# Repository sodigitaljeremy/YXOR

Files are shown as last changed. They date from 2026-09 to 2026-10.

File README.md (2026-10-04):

# YXOR

Robot humanoïde bipède autonome à IA embarquée locale.

> **À lire en premier : ce fichier (où en est le robot), puis
> [les décisions actives](docs/decisions.md) (ce qui est décidé, par
> qui).** La vision et la méthode sont dans [le cadrage](docs/cadrage.md).

## Où en est le robot — 2026-10-01

Le robot n'est pas dessiné à une taille choisie d'avance : **chaque
classe d'actionneur fixe la taille qu'elle porte** (`scripts/dimensionnement.py`,
marge 1,5). Quatre tailles :

| Taille | H | Actionneur de jambe | Statut |
| --- | --- | --- | --- |
| **S** | **0,60 m** (repli 0,55 m) | **RobStride RS02** au roulis et au tangage de hanche et au genou, **RS00** au lacet de hanche et au tangage de cheville ; 5 axes par jambe | **décidé** (fiches 0067 et 0068), premier robot |
| M | ~0,80 m | RS02 ou équivalent | ordre de grandeur |
| L | ~0,90 m | RS06, ou mixte RS06/RS02 | ordre de grandeur |
| XL | ≥ 1,0 m | RS03 et au-delà | hors programme |

Les hauteurs sont dans `params/anthropometry.yaml`.

**S, la v1 : 10 degrés de liberté**, 5 par jambe, sans bras : pas de
roulis de cheville (fiche 0068, Jeremy, 2026-10-04). Un degré de liberté
est une articulation motorisée.

- **Masse calculée : 6,75 kg à 0,60 m** en v1 (buste fixe), dont 1,2 kg
  de charge utile ; la jambe porterait jusqu'à 0,80 m. Avec l'hypothèse
  d'un haut du corps en RS05 (v3, 26 DDL) : 9,8 kg, 0,68 m portés.
  Actionneurs de jambe : 1 224 CHF HT. L'effort de roulis de cheville de
  la marche de référence est écarté, non reporté : hypothèse non vérifiée. La charge utile (calculateur,
  batterie, IMU) est une hypothèse de travail.
- **Le couple continu, la pointe, la charge utile et le relevé passent à
  0,60 m**, en v1 comme en v3 ; l'articulation limitante est le tangage
  de cheville. Grille et hypothèses :
  [`docs/choix-actionneurs.md`](docs/choix-actionneurs.md).
- **Restent ouverts** : la composition du banc, qui ne couvre que le
  RS00 ; une seconde marche de référence avant l'achat des 12 moteurs
  (proposé) ; la version exacte du RS00 (deux sont publiées) ; les tâches
  des bras ; les composants réels de la charge utile.

**Fabriqué à ce jour** : une pièce d'apprentissage, la semelle. Ni
assemblage ni nomenclature.

**La refonte du dépôt est terminée** (2026-10-01, étiquettes Git
`avant-refonte-2026-10-01` et `apres-refonte-2026-10-01`). Le diagnostic
qui l'a lancée est dans `archive/docs/`.

**Prochaine étape** (PROPOSÉE par Claude Code, non décidée) :

- la couche logicielle d'articulation et son backend MuJoCo, sans aucun
  achat ;
- puis la première pièce de jambe à H_S ;
- puis le banc de vérification du RS00 (`docs/protocole-banc.md`, critère
  outillé), dont la composition et l'achat se décident selon la fiche
  0066.

## Provenance et licences — *provisoire*

⚠ **Aucune licence pour l'instant.** C'est un choix délibéré de Jeremy,
le 2026-09-30 (fiche 0063), à rouvrir. Il n'y a pas de fichier `LICENSE`,
donc aucun droit n'est accordé au-delà des conditions de GitHub. Les
options étudiées sont dans `archive/docs/controle-publication-2026-09-30.md`
§ 3.

**Base de départ et référence de calcul :
[ToddlerBot](https://github.com/hshi74/toddlerbot)** (Stanford, 0,56 m).
Son code est sous MIT ; sa conception (les fichiers mécaniques) est sous
**CC BY-NC-SA 4.0**.

**Valeurs extraites de ToddlerBot.** Les fichiers ci-dessous contiennent
des valeurs numériques extraites de ToddlerBot : axes, butées, rapports de
transmission, masses, hauteur, noms d'articulations, empreintes des poids.

- `params/upstream_joints.generated.yaml` (extrait engendré) ;
- `params/joints.yaml` ;
- `params/ckpts.manifest.yaml` ;
- dans `params/actionneurs.yaml` et `params/anthropometry.yaml`, les
  seules entrées d'origine `amont`.

`scripts/provenance_amont.py` les compte.

Ces valeurs viennent de **ToddlerBot**, de Haochen Shi, Weizhuo Wang,
Shuran Song et C. Karen Liu (Stanford) :
<https://github.com/hshi74/toddlerbot>, commit `e337f3b`, article
arXiv:2502.00893. La conception de ToddlerBot est publiée sous
**[CC BY-NC-SA 4.0](https://creativecommons.org/licenses/by-nc-sa/4.0/)**,
son code sous MIT (© 2023 Haochen Shi). Par prudence, **ces fichiers sont
à traiter sous CC BY-NC-SA 4.0**, avec cette attribution. Les valeurs ont
été modifiées : réconciliées, renommées, qualifiées (fiches 0005 à 0007).

Savoir si des valeurs numériques isolées sont couvertes par cette licence
est une **question ouverte, sans avis** (fiche 0010 § 4). La mention
ci-dessus ne la tranche pas. **Aucune géométrie ToddlerBot n'entre dans
une pièce YXOR** (fiches 0055 et 0061).

**Autres fichiers tiers.** `sim/models/humanoid.xml` est le modèle
d'exemple de MuJoCo, © 2021 DeepMind Technologies Limited, sous
Apache-2.0. Son en-tête de licence est conservé.

## Principe

Aucun fichier binaire ne fait autorité. Toute géométrie se régénère depuis
le texte source. Le dépôt contient le **code des pièces**, jamais les
pièces.

Les contrôles qui protègent le robot ont chacun une commande qui échoue
quand la règle est enfreinte. La liste est dans `CLAUDE.md`, « Les
contrôles ».

## Commandes

```sh
.venv/bin/python scripts/regenerer.py          # tout : pièces, site, contrôles
.venv/bin/python -m unittest discover -s tests -v    # tests, à chaque clôture
.venv/bin/python scripts/choix_actionneurs.py --ecrire   # grille de S
.venv/bin/python scripts/dimensionnement.py    # taille portée par chaque classe
.venv/bin/python scripts/empreinte.py          # à comparer au pied de page du site
```

`regenerer.py` est la seule commande à connaître :

- il exécute les pièces ;
- il vérifie le dépôt, la provenance amont, les noms d'articulations et
  le rayon minimal ;
- il engendre le site et contrôle sa structure HTML ;
- il **sort en erreur** si l'un des contrôles échoue.

⚠ Toujours `.venv/bin/python`, jamais `python`. Voir « Deux interpréteurs »
dans `CLAUDE.md` : `sim/upstream/` est le seul répertoire qui s'exécute
avec l'autre environnement, et il refuse de démarrer sous le mauvais.

## Arborescence

```
params/     source de vérité (anthropometry, hardware, joints, actionneurs, exigences_S…)
parts/      pièces paramétriques (Python) et leurs relevés d'origines
scripts/    régénération, dimensionnement, grille de S, plans de découpe, contrôles
tests/      unittest
web/        feuille de style et scripts du site (aucune dépendance, aucun CDN)
sim/        simulation ; sim/upstream/ = venv amont
decisions/  fiches écrites depuis la refonte ; decisions/archive/ = les 64 d'avant
docs/       décisions actives, cadrage, choix des actionneurs, protocole du banc, glossaire
journal/    journal de bord, 10 lignes au plus par lot
archive/    documents, scripts, paramètres et tests retirés (rien n'est supprimé)
site/       engendré — jamais versionné
exports/    engendré — jamais versionné
```

`robot/` et `bom/` sont vides : ils n'ont pas encore de premier contenu.

## Le site

`yxor.fr` est une **projection du dépôt**, engendrée à chaque déploiement
par le `Dockerfile`, en deux étages : construction, puis service. Il ne
contient aucune donnée propre : chaque valeur affichée vient d'un fichier
du dépôt. Voir `decisions/archive/0018-application-web.md`.

## Documents

- **[Décisions actives](docs/decisions.md)**
- [Choix de l'actionneur de S](docs/choix-actionneurs.md) : faits,
  approvisionnement, grille d'exigences
- [Cadrage](docs/cadrage.md) : vision et méthode
- [Protocole du banc](docs/protocole-banc.md)
- [Glossaire](docs/glossaire.md)
- [Lecture du modèle amont](docs/lecture-modele.md)
- [Instructions de travail](CLAUDE.md)

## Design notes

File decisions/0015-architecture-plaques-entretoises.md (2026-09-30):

# 0015 — Architecture en plaques et entretoises, découpe 2D seule

Date : 2026-09-28
Espèce : close
État : amendée
Statut : acceptée
Découle de : `0014-pas-d-imprimante-3d.md`
Amendée par : `0042-rayon-matiere-ou-geste.md` — la règle du rayon minimal ne décrit que ce que la MATIÈRE supporte, pas ce que le GESTE permet.
Amendée par : `0016-plaques-sans-precedent.md` — aucun projet open source accessible ne suit cette voie ; Solo, Bolt et Upkie sont imprimés en 3D.
Remplacée par : `0060-fabrication-sequencee-appliquee.md` — la découpe 2D n'est plus le procédé unique ; le carton n'est plus qu'une maquette.

## Contrainte posée

> YXOR doit être fabricable avec des moyens que Jeremy peut obtenir,
> acheter et utiliser facilement. **Pas de machine unique, pas de procédé
> exotique, pas de tolérance serrée.**

Trois procédés accessibles, **tous de la découpe 2D** :

| Procédé | Matériau | Où |
| --- | --- | --- |
| cutter | carton, carton-plume | chez Jeremy, immédiat |
| laser | contreplaqué | fablab |
| découpe métal | aluminium | chez le cousin |

## 1 — Ce que l'architecture permet et interdit, face à ToddlerBot

### Ce qu'elle permet, et que ToddlerBot ne permet pas

- **Itérer en quelques minutes, à coût nul.** Un cutter et du carton
  donnent une pièce d'essai le jour même. Une pièce imprimée demande des
  heures. Pour un débutant qui doit apprendre à juger une pièce, c'est
  décisif — c'est le rythme d'apprentissage qui change, pas le prix.
- **Trois matériaux, une seule géométrie.** Le même dessin sert de la
  maquette carton à la pièce aluminium. Voir §3.
- **Aucune dépendance à une machine possédée.** Un fablab ou un artisan
  se remplacent ; une imprimante en panne, non.
- **Des pièces planes de précision.** Une découpe laser tient mieux
  l'écart entre deux perçages qu'une pièce imprimée, qui se rétracte au
  refroidissement.

### Ce qu'elle interdit

- **Les volumes.** Une pièce plate ne peut pas loger un moteur, guider un
  câble ou porter un bossage. Ces fonctions se reportent sur
  l'**empilement** : des plaques parallèles, tenues à distance par des
  entretoises. D'où le nom de l'architecture.
- **Les formes organiques.** Tout se ramène à des profils plans extrudés
  d'une épaisseur constante.
- **Les logements de roulement obtenus directement.** `CLAUDE.md`
  l'interdisait déjà ; la règle devient centrale. Un roulement se monte
  dans un **palier rapporté** du commerce.
- **Les filetages.** Ni le contreplaqué ni le carton ne tiennent un
  filet. L'assemblage passe par **vis traversantes et écrous**, ce qui
  sert d'ailleurs la règle « démontable, aucun collage ».
- **La compacité.** Un empilement de plaques est plus encombrant qu'un
  volume imprimé équivalent. **Le robot sera plus large.**

### La conséquence à ne pas manquer

**Les inerties changent.** Une plaque ajourée n'a ni la masse ni la
répartition d'un volume imprimé. Les politiques amont ont été entraînées
avec une randomisation de masse de **±20 %** (`body_mass_range` dans
`env_config.json`) : au-delà, leur transfert n'est plus couvert.

Ce n'est pas une objection — c'est une **hypothèse testable**, et elle se
teste ici, gratuitement : remplacer les inerties dans le modèle MuJoCo et
relancer `sim/upstream/replay_policy.py`. Le robot marche encore, ou non.

## 2 — La topologie de la fiche 0005 reste-t-elle tenable ?

**Oui pour les articulations. Non pour douze transmissions.**

La distinction à cinq identités de la fiche 0013 rend la réponse
précise, et c'est exactement ce pour quoi elle a été construite.

### Ce qui tient : les `articulation`

Un axe de rotation, une plage angulaire, un ordre de chaînage — rien de
tout cela ne suppose un procédé. Une plaque peut porter le même axe
qu'un volume imprimé. **Les 30 articulations, leurs axes, leurs sens et
leurs butées restent valables.**

Les motifs de la fiche 0005 — ne pas changer d'un coup morphologie,
cinématique, espace d'action et compatibilité des politiques — portaient
sur la **simulation**, que rien n'invalide ici.

### Ce qui ne tient pas : douze `actionnement`

| Mécanisme | Articulations | Réalisable en découpe 2D ? |
| --- | --- | --- |
| couplage par engrenage | 9 | **non** — un engrenage n'est pas un profil plan |
| bielle à quatre barres | 1 (`neck_pitch`) | **oui** — des bielles sont des pièces plates, c'est même le cas d'école |
| différentiel à deux moteurs | 2 (`waist_*`) | **non** — engrenages coniques |
| prise directe | 18 | **oui** |

**Dix-neuf sur trente passent sans rien changer.** Neuf demandent un
engrenage, deux un différentiel.

Trois issues, à instruire pièce par pièce et non ici :

1. **Acheter l'engrenage.** Il devient une `interface`, comme une vis.
2. **Passer en prise directe.** L'`articulation` est préservée,
   l'`actionnement` change. Conséquence : le couple et la plage
   utile changent, la commande est à remettre à l'échelle.
3. **Renoncer au degré de liberté** en P1.

**Le fichier `joints.yaml` absorbe les trois sans rien casser** : c'est
le bloc `actionnement` qui bouge, pas le bloc `articulation`. La
séparation faite au chantier 3 paie ici pour la première fois.

## 3 — Un dessin, trois matériaux : ce qui doit changer

**Correction d'emblée : ce n'est pas un même DXF.** C'est un **même
modèle paramétrique**, d'où l'on **génère trois DXF**. Le DXF est une
sortie figée, sans paramètre ; croire qu'un seul fichier servira les
trois est le piège à éviter.

Cinq paramètres changent entre les trois, et **tous sont de nature
`procede`** au sens de la fiche 0013 :

| Paramètre | Cutter / carton | Laser / contreplaqué | Découpe métal / alu |
| --- | --- | --- | --- |
| **épaisseur** | 5 mm (carton-plume) | 3 mm | 3 mm |
| **saignée** | ≈ 0 (la lame écarte) | ≈ 0,1–0,3 mm | 0,2–1,5 mm selon le moyen |
| **rayon intérieur minimal** | ≈ 0, mais 0,5 × ép. = 2,5 mm pour ne pas déchirer | ≈ saignée/2 | ≈ diamètre du jet ou de l'outil / 2 |
| **largeur de voile minimale** | large — le carton se déchire | moyenne | fine |
| **fixation** | vis + **rondelles larges** des deux côtés | vis + écrou | vis + écrou, ou taraudage possible |

### Ce qui en découle pour le modèle

- **L'épaisseur pilote toute la géométrie d'assemblage.** Dans une
  architecture en plaques, chaque fente reçoit une languette d'épaisseur
  égale au matériau. Une épaisseur en dur produirait un assemblage qui ne
  monte que dans un seul matériau.
- **La saignée décale le tracé.** Non compensée, les perçages sortent
  trop grands et les languettes trop fines. Elle est propre au couple
  machine-matériau, donc **à mesurer sur une pièce d'essai**, jamais à
  supposer.
- **Le rayon intérieur minimal est le plus contraignant des trois.** Pour
  qu'un dessin serve les trois, il doit respecter **le maximum** des
  trois minima.
- **La fixation change de nature.** Une vis dans 5 mm de carton-plume
  arrache sans rondelle ; en aluminium 3 mm elle peut être taraudée.

### Recommandation

Concevoir **au plus contraignant** — le carton — et laisser les deux
autres hériter. L'inverse produit des pièces carton inutilisables, or
c'est le carton qui permet d'itérer vite.

## 4 — Ce que cela change pour la première pièce

**La semelle survit, et son choix se trouve renforcé.** Elle était déjà
plate, déjà destinée à la chaîne DXF, déjà sans interface.

Quatre changements :

1. **Elle se fait en carton, aujourd'hui, au cutter.** Plus besoin
   d'attendre le cousin ni un fablab. La boucle d'apprentissage se ferme
   dans la journée.
2. **L'épaisseur devient 5 mm** (carton-plume), donc le rayon intérieur
   minimal passe de 1,5 à **2,5 mm**. Le creux d'arche proposé reste
   valable, ses congés grossissent.
3. **Elle doit être dessinée pour les trois matériaux dès maintenant**,
   même si un seul est coupé — c'est ce qui éprouve la
   paramétrisation par l'épaisseur.
4. **Elle cesse d'être une pièce d'apprentissage isolée** et devient le
   prototype de la méthode : un modèle, un paramètre d'épaisseur, trois
   DXF.

## Décision

1. **YXOR est conçu en plaques et entretoises, découpe 2D exclusivement**,
   tant qu'aucun autre procédé n'est vérifié.
2. **Aucune cote d'assemblage n'est écrite en dur** : toutes dérivent de
   l'épaisseur et de la saignée, de nature `procede`.
3. **La saignée de chaque couple machine-matériau est mesurée**, jamais
   supposée, avant toute pièce destinée à être montée.
4. **La topologie de la fiche 0005 est maintenue au niveau
   `articulation`.** Les douze `actionnement` à engrenage ou différentiel
   sont rouverts, à instruire un par un.

## Conséquences

- Le transfert des politiques amont devient une **hypothèse à tester**,
  la randomisation de masse à ±20 % ne couvrant pas un changement
  d'architecture. Test faisable en simulation, sans rien fabriquer.
- Le robot sera **plus large** qu'un équivalent imprimé. À intégrer dès
  la conception, pas à découvrir au montage.
- `hardware.yaml` doit accueillir un bloc par **couple machine-matériau**,
  et non par procédé générique.

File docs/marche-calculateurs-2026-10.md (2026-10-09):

# Marché des calculateurs (2026-10)

**Engendré** par `.venv/bin/python scripts/marche_composants.py --ecrire`. Ne pas éditer à la main. **Données seulement** : aucune intégration à l'explorateur, aucun achat (fiche 0066). Contexte DÉCIDÉ (fiche 0070, Jeremy, 2026-10-07) : « Les deux robots, YXOR Lab et YXOR, fonctionnent entièrement sur batterie. Je préfère NVIDIA Jetson, mais je veux une comparaison chiffrée avec le Raspberry Pi 5 et ses cartes d'IA. » Sources lues le 2026-10-07, téléchargées hors du dépôt, inscrites à `params/fournisseurs.yaml` (non redistribuables) ; une valeur non lue est un trou (—), jamais estimée.

31 produits, 73 sources.

## Mises en garde sur les TOPS

- NVIDIA Orin : « AI Performance » = INT8 SPARSE, GPU + DLA additionnés. Le dense vaut la moitié ; GPU seul en INT8 dense : Nano 4GB 17, Nano 8GB 33, NX 38, AGX 32GB 54, AGX 64GB 85, Industrial 78.
- La page du kit Orin Nano Super écrit « 67 INT8 TOPS » sans le mot sparse ; le fiche J401 de Seeed donne encore les TOPS d'avant Super (20/40/70/100).
- NVIDIA Thor (T2000–T5000) : TFLOPS FP4 SPARSE seulement, aucune valeur INT8 publiée sur les pages lues ; « 7.5x AGX Orin » compare FP4 sparse à INT8 sparse.
- AI HAT+ 2 (Hailo-10H) : 40 TOPS en INT4 ; vision « comparable » à l'AI HAT+ 26 TOPS.
- Hailo-8 / 8L (AI HAT+) : précision et parcimonie non publiées par Raspberry Pi.
- AGX Orin 32GB : la même page NVIDIA donne 241 puis 200 TOPS : 200 retenu.

Seuls les TOPS **INT8 dense** se comparent : colonne « dense ». Le chiffre affiché par le fabricant est donné à côté, avec sa précision.

## Les produits

| Produit | Famille | TOPS dense | TOPS affichés (précision) | W max | TOPS/W | CHF HT | TOPS/CHF | CAN intégré |
| --- | --- | ---: | --- | ---: | ---: | ---: | ---: | --- |
| Jetson AGX Thor Developer Kit | jetson_kit | — | 2 070 (FP4 sparse (TFLOPS)) | 130 | — | 4 590 | — | oui (2) |
| Jetson AGX Orin Developer Kit (64GB) | jetson_kit | — | 275 (INT8 sparse (GPU + DLA)) | 60 | — | 2 921 | — | oui |
| Seeed reComputer Mini J3011 (Orin Nano 8 GB inclus) | jetson_kit | 33 | 67 (INT8 sparse (GPU + DLA)) | 25 | 1,32 | 500 | 0,066 | oui (2) |
| Jetson Orin Nano Super Developer Kit | jetson_kit | — | 67 (INT8 sparse) | 25 | — | 333 | — | — |
| Jetson T5000 (Jetson AGX Thor) | jetson_module | — | 2 070 (FP4 sparse (TFLOPS)) | 130 | — | 4 173 | — | oui (4) |
| Jetson T4000 | jetson_module | — | 1 200 (FP4 sparse (TFLOPS)) | 75 | — | 2 503 | — | — |
| Jetson T3000 (et IGX Thor T3000) | jetson_module | — | 865 (FP4 sparse (TFLOPS)) | — | — | — | — | — |
| Jetson T2000 | jetson_module | — | 400 (FP4 sparse (TFLOPS)) | — | — | — | — | — |
| Jetson AGX Orin 64GB | jetson_module | 85 | 275 (INT8 sparse (GPU + DLA)) | 60 | 1,42 | 2 503 | 0,034 | oui (2) |
| Jetson AGX Orin Industrial (64GB, ECC) | jetson_module | 78 | 248 (INT8 sparse (GPU + DLA)) | 75 | 1,04 | 2 670 | 0,029 | oui (2) |
| Jetson AGX Orin 32GB | jetson_module | 54 | 200 (INT8 sparse (GPU + DLA)) | 60 | 0,90 | 1 502 | 0,036 | oui (2) |
| Jetson Orin NX 16GB (Super) | jetson_module | 38 | 157 (INT8 sparse (GPU + DLA)) | 40 | 0,95 | 834 | 0,046 | oui (1) |
| Jetson Orin NX 8GB (Super) | jetson_module | 38 | 117 (INT8 sparse (GPU + DLA)) | 40 | 0,95 | 542 | 0,070 | oui (1) |
| Jetson Orin Nano 8GB (Super) | jetson_module | 33 | 67 (INT8 sparse (GPU + DLA)) | 25 | 1,32 | 333 | 0,099 | oui (1) |
| Jetson Orin Nano 4GB (Super) | jetson_module | 17 | 34 (INT8 sparse (GPU + DLA)) | 25 | 0,68 | 291 | 0,058 | oui (1) |
| reComputer J401 (carte seule) | porteuse | — | — (—) | — | — | — | — | oui (1) |
| reComputer Super (J40xx/J30xx, boîtier complet) | porteuse | — | — (—) | — | — | — | — | oui (1) |
| reComputer Mini (porteuse Mini J401, boîtier) | porteuse | — | — (—) | — | — | — | — | oui (2) |
| Hadron Carrier (NGX012) | porteuse | — | — (—) | — | — | 301 | — | — |
| Boson for FRAMOS Carrier (NGX020) | porteuse | — | — (—) | — | — | 513 | — | — |
| JNX120S | porteuse | — | — (—) | — | — | 170 | — | oui (1) |
| JNX120M | porteuse | — | — (—) | — | — | 208 | — | oui (1) |
| Raspberry Pi 5 4GB | rpi | — | — (—) | — | — | 92 | — | non |
| Raspberry Pi 5 8GB | rpi | — | — (—) | — | — | 146 | — | non |
| Raspberry Pi 5 16GB | rpi | — | — (—) | — | — | 255 | — | non |
| Raspberry Pi Compute Module 5 | rpi | — | — (—) | — | — | 159 | — | non |
| Raspberry Pi AI HAT+ 2 | rpi_ia | — | 40 (INT4) | — | — | 167 | — | non |
| Raspberry Pi AI HAT+ 26 TOPS | rpi_ia | — | 26 (non précisée (« 26 TOPS inferencing performance »)) | — | — | 92 | — | non |
| Raspberry Pi AI HAT+ 13 TOPS | rpi_ia | — | 13 (non précisée (« 13 TOPS inferencing performance »)) | — | — | 58 | — | non |
| Raspberry Pi AI Kit (M.2 HAT+ et module Hailo-8L) | rpi_ia | — | 13 (non précisée) | — | — | — | — | non |
| Raspberry Pi AI Camera (pour information) | rpi_ia | — | — (entrées int8 ou uint8) | — | — | 58 | — | non |

## Les plus pertinents pour un robot de 10 kg

Critères PROPOSÉS : puissance maximale ≤ 25 W (ou non publiée, DIT) ; produits en vente (annoncés et fin de production exclus) ; classés par TOPS INT8 dense, puis TOPS affichés, puis prix. Un MODULE Jetson seul exige une carte porteuse (famille « porteuse » ci-dessus), NON comptée dans son prix ni dans sa masse.

| # | Produit | TOPS dense | TOPS affichés | W max | CHF HT | CAN intégré |
| ---: | --- | ---: | --- | ---: | ---: | --- |
| 1 | Jetson Orin Nano 8GB (Super) | 33 | 67 (INT8 sparse (GPU + DLA)) | 25 | 333 | oui |
| 2 | Seeed reComputer Mini J3011 (Orin Nano 8 GB inclus) | 33 | 67 (INT8 sparse (GPU + DLA)) | 25 | 500 | oui |
| 3 | Jetson Orin Nano 4GB (Super) | 17 | 34 (INT8 sparse (GPU + DLA)) | 25 | 291 | oui |
| 4 | Jetson Orin Nano Super Developer Kit | — | 67 (INT8 sparse) | 25 | 333 | — |
| 5 | Raspberry Pi 5 8GB + Raspberry Pi AI HAT+ 2 | — | 40 (INT4) | non publiée | 313 | non |
| 6 | Raspberry Pi 5 8GB + Raspberry Pi AI HAT+ 26 TOPS | — | 26 (non précisée (« 26 TOPS inferencing performance »)) | non publiée | 238 | non |
| 7 | Raspberry Pi 5 8GB + Raspberry Pi AI HAT+ 13 TOPS | — | 13 (non précisée (« 13 TOPS inferencing performance »)) | non publiée | 205 | non |
| 8 | Raspberry Pi 5 8GB + Raspberry Pi AI Camera (pour information) | — | — (entrées int8 ou uint8) | non publiée | 205 | non |

## Les plus pertinents pour un robot de 35 kg

Critères PROPOSÉS : puissance maximale ≤ 75 W (ou non publiée, DIT) ; produits en vente (annoncés et fin de production exclus) ; classés par TOPS INT8 dense, puis TOPS affichés, puis prix. Un MODULE Jetson seul exige une carte porteuse (famille « porteuse » ci-dessus), NON comptée dans son prix ni dans sa masse.

| # | Produit | TOPS dense | TOPS affichés | W max | CHF HT | CAN intégré |
| ---: | --- | ---: | --- | ---: | ---: | --- |
| 1 | Jetson AGX Orin 64GB | 85 | 275 (INT8 sparse (GPU + DLA)) | 60 | 2 503 | oui |
| 2 | Jetson AGX Orin Industrial (64GB, ECC) | 78 | 248 (INT8 sparse (GPU + DLA)) | 75 | 2 670 | oui |
| 3 | Jetson AGX Orin 32GB | 54 | 200 (INT8 sparse (GPU + DLA)) | 60 | 1 502 | oui |
| 4 | Jetson Orin NX 16GB (Super) | 38 | 157 (INT8 sparse (GPU + DLA)) | 40 | 834 | oui |
| 5 | Jetson Orin NX 8GB (Super) | 38 | 117 (INT8 sparse (GPU + DLA)) | 40 | 542 | oui |
| 6 | Jetson Orin Nano 8GB (Super) | 33 | 67 (INT8 sparse (GPU + DLA)) | 25 | 333 | oui |
| 7 | Seeed reComputer Mini J3011 (Orin Nano 8 GB inclus) | 33 | 67 (INT8 sparse (GPU + DLA)) | 25 | 500 | oui |
| 8 | Jetson Orin Nano 4GB (Super) | 17 | 34 (INT8 sparse (GPU + DLA)) | 25 | 291 | oui |

## Marché en 2026

- Hausse NVIDIA de juillet 2026 (jusqu'à +101 %), ex. kit Orin Nano Super 249 $ → 399 $ (nv_faq, cnx_prix).
- Fin de vie accélérée des Jetson LPDDR4 (TX2 NX, TX2i, AGX Xavier, Xavier NX), dernière livraison 15/07/2027 (cnx_lpddr4_eol).
- Nouveautés 2026 : T4000 (en vente), T3000 et T2000 annoncés pour T1 2027 ; AI HAT+ 2 (Hailo-10H) ; brief RPi 5 d'octobre 2026 (16GB à 305 $).
- Raspberry Pi AI Kit : fin de production.

## Trous

- Masses des modules Jetson et des kits NVIDIA : non publiées sur les pages lues (fiches techniques derrière inscription).
- Consommation au repos et typique : aucune valeur fabricant pour Jetson ni Raspberry Pi (seulement des plages de modes).
- Hailo-8 M.2 seul et pages hailo.ai : bloquées (403), non relevées.
- Pages raspberrypi.com, pi-shop.ch, digitec.ch, connecttech.com : protection anti-robot, non téléchargées. Aucun prix suisse relevé.
- ONNX Runtime : non vérifié. Tensions d'entrée des kits NVIDIA : non lues.

TOPS par watt et par franc

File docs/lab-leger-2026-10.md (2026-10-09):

# Un YXOR Lab léger, pour apprendre à marcher (2026-10)

**Engendré** par `.venv/bin/python scripts/lab_leger.py --ecrire`. **Étude, AUCUNE décision** : le profil `lab_leger` (`params/capacites.yaml`) est un CANDIDAT PROPOSÉ ; il ne remplace pas le profil lab.

Question de Jeremy (2026-10-08) : « Est-ce que l'étude et ce que nous avions déterminé pour YXOR Lab ne représente-t-il pas mieux YXOR Home finalement ? Est-ce qu'il n'existerait pas une meilleure version de YXOR Lab plus optimisée et compatible avec YXOR Kit ? »

Profil : marche sur sol plat 0,10, 0,15 ou 0,3 m/s, relevé sur le dos et sur le ventre, gestes 0,5 m/s, tête à 2 axes, IA « + vision », autonomie 20 min (la plus exigeante de 10 et 20). Hors profil : saut, poussée, saisie, sol irrégulier, pente. Méthode : en tête de `scripts/lab_leger.py`.

## En bref

- **Marge 1,5** : aucune famille ne tient la marche entre 0,35 et 0,65 m.
- **Marge 1,0** : aucune famille ne tient la marche entre 0,35 et 0,65 m.
- **Retiré le 2026-10-09 : « Feetech en carton tient à la marge 1,0 »** (version du 2026-10-08). Ce résultat reposait sur la vitesse INCONNUE du STS3250 au catalogue de l'explorateur, et la règle comptait INCONNU comme « tient ». Désormais : la vitesse du STS3250 vient de sa fiche candidate (7,9 rad/s), et une donnée critique d'actionneur manquante (vitesse, couple continu) donne INCONNU, jamais « tient ».
- **Les vitesses requises viennent de marches simulées plus rapides que la vitesse étudiée** (section « Marcher lentement ») : à 0,10, 0,15 et 0,30 m/s, aucune marche simulée n'existe à cette taille ; la règle de l'explorateur prend la plus exigeante des marches au moins aussi rapides (G1, 0,55 m/s).
- **Robot entier avec la règle « plus_lente »** (PROPOSÉE, NON adoptée, section dédiée) : à la marge 1,5, rien ne tient ; à la marge 1,0, seuls A en carton (STS3250 aux jambes) et B en carton (RS05/EduLite05) tiennent.
- **Le Lab actuel** (« Home candidat ») : 0,850 m, 18,5 kg, ≥ 4 514 CHF, 87 J à la chute.

## La plus petite H où la marche tient, par famille

« Tient » : faisable, ou INCONNU seulement par les bornes proposées du système électrique (communes à toutes les solutions), toutes capacités couvertes ; une donnée critique d'actionneur manquante (vitesse, couple continu) donne INCONNU, jamais « tient » (règle du 2026-10-09). Besoins de marche : règle de l'explorateur (voir « Marcher lentement »). Coût : borne basse, CHF HT (prix connus seulement). Énergie de chute : M·g·hauteur du centre de gravité. Part du Kit : coût connu de l'option progressive (`scripts/kit.py`) qui resservirait.

| Marge | Jambes | Structure | Marche (m/s) | H → réelle (m) | Masse (kg) | Coût (CHF) | Chute (J) | Statut | Part du Kit réutilisée | Ce qui resservirait |
| ---: | --- | --- | ---: | --- | ---: | ---: | ---: | --- | ---: | --- |
| 1,5 | feetech | alu 2 mm évidé | 0,10 | **ne tient à aucune H** de 0,35 à 0,65 m (bloquent : knee) | — | — | — | — | — | — |
| 1,5 | feetech | alu 2 mm évidé | 0,15 | **ne tient à aucune H** de 0,35 à 0,65 m (bloquent : knee) | — | — | — | — | — | — |
| 1,5 | feetech | alu 2 mm évidé | 0,30 | **ne tient à aucune H** de 0,35 à 0,65 m (bloquent : knee) | — | — | — | — | — | — |
| 1,5 | feetech | carton | 0,10 | **ne tient à aucune H** de 0,35 à 0,65 m (bloquent : knee) | — | — | — | — | — | — |
| 1,5 | feetech | carton | 0,15 | **ne tient à aucune H** de 0,35 à 0,65 m (bloquent : knee) | — | — | — | — | — | — |
| 1,5 | feetech | carton | 0,30 | **ne tient à aucune H** de 0,35 à 0,65 m (bloquent : knee) | — | — | — | — | — | — |
| 1,5 | dynamixel | alu 2 mm évidé | 0,10 | **ne tient à aucune H** de 0,35 à 0,65 m (bloquent : hip_pitch, knee) | — | — | — | — | — | — |
| 1,5 | dynamixel | alu 2 mm évidé | 0,15 | **ne tient à aucune H** de 0,35 à 0,65 m (bloquent : hip_pitch, knee) | — | — | — | — | — | — |
| 1,5 | dynamixel | alu 2 mm évidé | 0,30 | **ne tient à aucune H** de 0,35 à 0,65 m (bloquent : hip_pitch, knee) | — | — | — | — | — | — |
| 1,5 | dynamixel | carton | 0,10 | **ne tient à aucune H** de 0,35 à 0,65 m (bloquent : ankle_pitch, knee) | — | — | — | — | — | — |
| 1,5 | dynamixel | carton | 0,15 | **ne tient à aucune H** de 0,35 à 0,65 m (bloquent : ankle_pitch, knee) | — | — | — | — | — | — |
| 1,5 | dynamixel | carton | 0,30 | **ne tient à aucune H** de 0,35 à 0,65 m (bloquent : ankle_pitch, knee) | — | — | — | — | — | — |
| 1,5 | robstride | alu 2 mm évidé | 0,10 | **ne tient à aucune H** de 0,35 à 0,65 m (bloquent : hip_pitch, hip_roll, hip_yaw, knee) | — | — | — | — | — | — |
| 1,5 | robstride | alu 2 mm évidé | 0,15 | **ne tient à aucune H** de 0,35 à 0,65 m (bloquent : hip_pitch, hip_roll, hip_yaw, knee) | — | — | — | — | — | — |
| 1,5 | robstride | alu 2 mm évidé | 0,30 | **ne tient à aucune H** de 0,35 à 0,65 m (bloquent : hip_pitch, hip_roll, hip_yaw, knee) | — | — | — | — | — | — |
| 1,5 | robstride | carton | 0,10 | **ne tient à aucune H** de 0,35 à 0,65 m (bloquent : hip_pitch, hip_roll, hip_yaw, knee) | — | — | — | — | — | — |
| 1,5 | robstride | carton | 0,15 | **ne tient à aucune H** de 0,35 à 0,65 m (bloquent : hip_pitch, hip_roll, hip_yaw, knee) | — | — | — | — | — | — |
| 1,5 | robstride | carton | 0,30 | **ne tient à aucune H** de 0,35 à 0,65 m (bloquent : hip_pitch, hip_roll, hip_yaw, knee) | — | — | — | — | — | — |
| 1,0 | feetech | alu 2 mm évidé | 0,10 | **ne tient à aucune H** de 0,35 à 0,65 m (bloquent : knee) | — | — | — | — | — | — |
| 1,0 | feetech | alu 2 mm évidé | 0,15 | **ne tient à aucune H** de 0,35 à 0,65 m (bloquent : knee) | — | — | — | — | — | — |
| 1,0 | feetech | alu 2 mm évidé | 0,30 | **ne tient à aucune H** de 0,35 à 0,65 m (bloquent : knee) | — | — | — | — | — | — |
| 1,0 | feetech | carton | 0,10 | **ne tient à aucune H** de 0,35 à 0,65 m (bloquent : knee) | — | — | — | — | — | — |
| 1,0 | feetech | carton | 0,15 | **ne tient à aucune H** de 0,35 à 0,65 m (bloquent : knee) | — | — | — | — | — | — |
| 1,0 | feetech | carton | 0,30 | **ne tient à aucune H** de 0,35 à 0,65 m (bloquent : knee) | — | — | — | — | — | — |
| 1,0 | dynamixel | alu 2 mm évidé | 0,10 | **ne tient à aucune H** de 0,35 à 0,65 m (bloquent : ankle_pitch, knee) | — | — | — | — | — | — |
| 1,0 | dynamixel | alu 2 mm évidé | 0,15 | **ne tient à aucune H** de 0,35 à 0,65 m (bloquent : ankle_pitch, knee) | — | — | — | — | — | — |
| 1,0 | dynamixel | alu 2 mm évidé | 0,30 | **ne tient à aucune H** de 0,35 à 0,65 m (bloquent : ankle_pitch, knee) | — | — | — | — | — | — |
| 1,0 | dynamixel | carton | 0,10 | **ne tient à aucune H** de 0,35 à 0,65 m (bloquent : ankle_pitch, knee) | — | — | — | — | — | — |
| 1,0 | dynamixel | carton | 0,15 | **ne tient à aucune H** de 0,35 à 0,65 m (bloquent : ankle_pitch, knee) | — | — | — | — | — | — |
| 1,0 | dynamixel | carton | 0,30 | **ne tient à aucune H** de 0,35 à 0,65 m (bloquent : ankle_pitch, knee) | — | — | — | — | — | — |
| 1,0 | robstride | alu 2 mm évidé | 0,10 | **ne tient à aucune H** de 0,35 à 0,65 m (bloquent : hip_pitch, hip_roll, hip_yaw, knee) | — | — | — | — | — | — |
| 1,0 | robstride | alu 2 mm évidé | 0,15 | **ne tient à aucune H** de 0,35 à 0,65 m (bloquent : hip_pitch, hip_roll, hip_yaw, knee) | — | — | — | — | — | — |
| 1,0 | robstride | alu 2 mm évidé | 0,30 | **ne tient à aucune H** de 0,35 à 0,65 m (bloquent : hip_pitch, hip_roll, hip_yaw, knee) | — | — | — | — | — | — |
| 1,0 | robstride | carton | 0,10 | **ne tient à aucune H** de 0,35 à 0,65 m (bloquent : hip_pitch, hip_roll, hip_yaw, knee) | — | — | — | — | — | — |
| 1,0 | robstride | carton | 0,15 | **ne tient à aucune H** de 0,35 à 0,65 m (bloquent : hip_pitch, hip_roll, hip_yaw, knee) | — | — | — | — | — | — |
| 1,0 | robstride | carton | 0,30 | **ne tient à aucune H** de 0,35 à 0,65 m (bloquent : hip_pitch, hip_roll, hip_yaw, knee) | — | — | — | — | — | — |

## La moins chère par famille (marche 0,3 m/s) : le prix de chaque famille

| Marge | Jambes | Structure | H → réelle (m) | Masse (kg) | Coût (CHF) | Chute (J) | Actionneurs des jambes |
| ---: | --- | --- | --- | ---: | ---: | ---: | --- |

## Marcher lentement : les besoins par articulation (H = 0,60 m, 3,45 kg)

Les trois marches simulées, ramenées à 0,60 m : ToddlerBot à 0,196 m/s ; Unitree G1 à 0,547 m/s ; Booster T1 à 0,690 m/s. **Aucune ne va à 0,10, 0,15 ou 0,30 m/s** : à ces vitesses, la donnée est null et le statut INCONNU. Deux lectures sont montrées, sans interpolation : la règle de l'explorateur (le maximum des marches au moins aussi rapides) et la marche la plus lente au moins aussi rapide (une borne haute). Les autres tâches du profil (relevé, gestes, tête) s'ajoutent (maximum par axe).

| Vitesse (m/s) | Lecture | Source | Genou : pointe (N·m), vitesse (rad/s) | Cheville : pointe, vitesse | Tangage de hanche : pointe, vitesse |
| ---: | --- | --- | --- | --- | --- |
| 0,10 | donnée à cette vitesse | aucune | null (INCONNU) | null (INCONNU) | null (INCONNU) |
| 0,10 | règle de l'explorateur | ToddlerBot (0.196 m/s), Unitree G1 (0.547 m/s), Booster T1 (0.690 m/s) | 2,90, 14,1 | 2,35, 18,2 | 2,72, 6,0 |
| 0,10 | la plus lente au-dessus (borne) | ToddlerBot (0.196 m/s) | 2,03, 4,6 | 2,35, 2,5 | 2,35, 3,4 |
| 0,15 | donnée à cette vitesse | aucune | null (INCONNU) | null (INCONNU) | null (INCONNU) |
| 0,15 | règle de l'explorateur | ToddlerBot (0.196 m/s), Unitree G1 (0.547 m/s), Booster T1 (0.690 m/s) | 2,90, 14,1 | 2,35, 18,2 | 2,72, 6,0 |
| 0,15 | la plus lente au-dessus (borne) | ToddlerBot (0.196 m/s) | 2,03, 4,6 | 2,35, 2,5 | 2,35, 3,4 |
| 0,30 | donnée à cette vitesse | aucune | null (INCONNU) | null (INCONNU) | null (INCONNU) |
| 0,30 | règle de l'explorateur | Unitree G1 (0.547 m/s), Booster T1 (0.690 m/s) | 2,90, 14,1 | 1,11, 18,2 | 2,72, 6,0 |
| 0,30 | la plus lente au-dessus (borne) | Unitree G1 (0.547 m/s) | 2,90, 14,1 | 1,11, 18,2 | 2,72, 5,7 |

**0,15 m/s reprend-elle un niveau voisin ?** Avec la règle de l'explorateur, OUI pour les vitesses : les vitesses requises sont identiques à celles de 0,30 m/s, parce que le maximum inclut le G1 et le T1, qui marchent bien plus vite (0,55 et 0,69 m/s à cette taille) ; seuls des couples diffèrent (ceux de ToddlerBot, plus forts à la cheville). La borne « la plus lente au-dessus » donne, elle, les besoins de ToddlerBot (0,196 m/s) à 0,10 et 0,15 m/s.

### Verdict par actionneur, même actionneur sur les cinq axes de jambe (marge 1,5 sur le couple)

| Actionneur | 0,10 m/s (borne) | 0,15 m/s (borne) | 0,30 m/s (borne) | ToddlerBot (0,196 m/s, donnée) | Unitree G1 (0,547 m/s, donnée) | Booster T1 (0,690 m/s, donnée) |
| --- | --- | --- | --- | --- | --- | --- |
| sts3215_c018 (Feetech, 12 V) | INCONNU (au-dessus de la borne) | INCONNU (au-dessus de la borne) | INCONNU (au-dessus de la borne) | ne tient pas | ne tient pas | ne tient pas |
| sts3250 (Feetech, 12 V) | tient (sous la borne) | tient (sous la borne) | INCONNU (au-dessus de la borne) | tient | ne tient pas | ne tient pas |
| HTD-85H (Hiwonder, 11.1 V) | INCONNU (donnée d'actionneur manquante) | INCONNU (donnée d'actionneur manquante) | INCONNU (au-dessus de la borne) | INCONNU (donnée d'actionneur manquante) | ne tient pas | ne tient pas |
| RSBL120-24 (Waveshare, ?) | INCONNU (donnée d'actionneur manquante) | INCONNU (donnée d'actionneur manquante) | INCONNU (au-dessus de la borne) | INCONNU (donnée d'actionneur manquante) | ne tient pas | ne tient pas |
| KRS-9304HV ICS (Kondo, 11.1 V) | INCONNU (au-dessus de la borne) | INCONNU (au-dessus de la borne) | INCONNU (au-dessus de la borne) | ne tient pas | ne tient pas | ne tient pas |
| DRS-0601 (HerkuleX, 14.8 V) | INCONNU (donnée d'actionneur manquante) | INCONNU (donnée d'actionneur manquante) | INCONNU (au-dessus de la borne) | INCONNU (donnée d'actionneur manquante) | ne tient pas | ne tient pas |
| LSS-HT1 (Lynxmotion LSS, 12 V) | INCONNU (au-dessus de la borne) | INCONNU (au-dessus de la borne) | INCONNU (au-dessus de la borne) | ne tient pas | ne tient pas | ne tient pas |
| RS305CR (Futaba RS (commande), ?) | INCONNU (au-dessus de la borne) | INCONNU (au-dessus de la borne) | INCONNU (au-dessus de la borne) | ne tient pas | ne tient pas | ne tient pas |
| UBT-12HC (servo de l’Alpha 1S) (UBTECH, 8.5 V) | INCONNU (au-dessus de la borne) | INCONNU (au-dessus de la borne) | INCONNU (au-dessus de la borne) | ne tient pas | ne tient pas | ne tient pas |
| rs05 (RobStride, 12S, 3,0 V/cellule) | tient (sous la borne) | tient (sous la borne) | INCONNU (au-dessus de la borne) | tient | ne tient pas | ne tient pas |
| edulite05 (RobStride, 12S, 3,0 V/cellule) | tient (sous la borne) | tient (sous la borne) | INCONNU (au-dessus de la borne) | tient | ne tient pas | tient |

### Verdict par actionneur, même actionneur sur les cinq axes de jambe (marge 1,0 sur le couple)

| Actionneur | 0,10 m/s (borne) | 0,15 m/s (borne) | 0,30 m/s (borne) | ToddlerBot (0,196 m/s, donnée) | Unitree G1 (0,547 m/s, donnée) | Booster T1 (0,690 m/s, donnée) |
| --- | --- | --- | --- | --- | --- | --- |
| sts3215_c018 (Feetech, 12 V) | INCONNU (au-dessus de la borne) | INCONNU (au-dessus de la borne) | INCONNU (au-dessus de la borne) | ne tient pas | ne tient pas | ne tient pas |
| sts3250 (Feetech, 12 V) | tient (sous la borne) | tient (sous la borne) | INCONNU (au-dessus de la borne) | tient | ne tient pas | ne tient pas |
| HTD-85H (Hiwonder, 11.1 V) | INCONNU (donnée d'actionneur manquante) | INCONNU (donnée d'actionneur manquante) | INCONNU (au-dessus de la borne) | INCONNU (donnée d'actionneur manquante) | ne tient pas | ne tient pas |
| RSBL120-24 (Waveshare, ?) | INCONNU (donnée d'actionneur manquante) | INCONNU (donnée d'actionneur manquante) | INCONNU (au-dessus de la borne) | INCONNU (donnée d'actionneur manquante) | ne tient pas | ne tient pas |
| KRS-9304HV ICS (Kondo, 11.1 V) | INCONNU (au-dessus de la borne) | INCONNU (au-dessus de la borne) | INCONNU (au-dessus de la borne) | ne tient pas | ne tient pas | ne tient pas |
| DRS-0601 (HerkuleX, 14.8 V) | INCONNU (donnée d'actionneur manquante) | INCONNU (donnée d'actionneur manquante) | INCONNU (au-dessus de la borne) | INCONNU (donnée d'actionneur manquante) | ne tient pas | ne tient pas |
| LSS-HT1 (Lynxmotion LSS, 12 V) | INCONNU (au-dessus de la borne) | INCONNU (au-dessus de la borne) | INCONNU (au-dessus de la borne) | ne tient pas | ne tient pas | ne tient pas |
| RS305CR (Futaba RS (commande), ?) | INCONNU (au-dessus de la borne) | INCONNU (au-dessus de la borne) | INCONNU (au-dessus de la borne) | ne tient pas | ne tient pas | ne tient pas |
| UBT-12HC (servo de l’Alpha 1S) (UBTECH, 8.5 V) | INCONNU (au-dessus de la borne) | INCONNU (au-dessus de la borne) | INCONNU (au-dessus de la borne) | ne tient pas | ne tient pas | ne tient pas |
| rs05 (RobStride, 12S, 3,0 V/cellule) | tient (sous la borne) | tient (sous la borne) | tient (sous la borne) | tient | tient | tient |
| edulite05 (RobStride, 12S, 3,0 V/cellule) | tient (sous la borne) | tient (sous la borne) | tient (sous la borne) | tient | tient | tient |

### Marges à 0,10 m/s (borne : ToddlerBot (0.196 m/s)) : couple de pointe / couple continu / vitesse

Chaque case : rapport « publié ÷ requis » ; le couple doit atteindre la marge (1,5 ou 1,0), la vitesse 1,0. « — » : donnée non publiée (INCONNU).

| Axe | Requis : pointe, continu (N·m), vitesse (rad/s) | sts3215_c018 | sts3250 | HTD-85H | RSBL120-24 | KRS-9304HV ICS | DRS-0601 | LSS-HT1 | RS305CR | UBT-12HC (servo de l’Alpha 1S) | rs05 | edulite05 |
| --- | --- | --- | --- | --- | --- | --- | --- | --- | --- | --- | --- | --- |
| hip_pitch | 2,35, 0,70, 3,4 (marche) | 1,25 / 1,40 / 1,39 | 2,08 / 2,24 / 2,31 | 3,54 / — / 1,54 | 5,00 / — / 1,54 | 3,79 / — / 1,34 | 3,21 / — / 1,92 | 1,21 / 0,81 / 1,85 | 0,30 / — / 2,80 | 0,50 / — / 1,55 | 2,34 / 2,28 / 11,08 | 2,34 / 2,56 / 9,93 |
| hip_roll | 2,34, 0,94, 2,2 (marche) | 1,26 / 1,05 / 2,11 | 2,09 / 1,68 / 3,53 | 3,56 / — / 2,35 | 5,02 / — / 2,35 | 3,80 / — / 2,04 | 3,22 / — / 2,94 | 1,21 / 0,61 / 2,82 | 0,30 / — / 4,27 | 0,50 / — / 2,37 | 2,35 / 1,71 / 16,91 | 2,35 / 1,92 / 15,14 |
| hip_yaw | 1,12, 0,32, 2,5 (marche) | 2,63 / 3,09 / 1,89 | 4,38 / 4,95 / 3,15 | 7,44 / — / 2,10 | 10,51 / — / 2,10 | 7,96 / — / 1,82 | 6,74 / — / 2,62 | 2,54 / 1,79 / 2,52 | 0,62 / — / 3,81 | 1,05 / — / 2,12 | 4,91 / 5,04 / 15,10 | 4,91 / 5,67 / 13,52 |
| knee | 2,03, 0,52, 4,6 (marche) | 1,45 / 1,89 / 1,03 | 2,42 / 3,02 / 1,72 | 4,11 / — / 1,14 | 5,80 / — / 1,14 | 4,40 / — / 0,99 | 3,72 / — / 1,43 | 1,40 / 1,09 / 1,37 | 0,34 / — / 2,07 | 0,58 / — / 1,15 | 2,71 / 3,08 / 8,21 | 2,71 / 3,46 / 7,36 |
| ankle_pitch | 2,35, 0,99, 2,5 (marche) | 1,25 / 1,00 / 1,87 | 2,08 / 1,59 / 3,12 | 3,54 / — / 2,08 | 5,00 / — / 2,08 | 3,79 / — / 1,80 | 3,21 / — / 2,59 | 1,21 / 0,58 / 2,49 | 0,30 / — / 3,77 | 0,50 / — / 2,10 | 2,34 / 1,62 / 14,94 | 2,34 / 1,83 / 13,39 |

### Marges à 0,15 m/s (borne : ToddlerBot (0.196 m/s)) : couple de pointe / couple continu / vitesse

Chaque case : rapport « publié ÷ requis » ; le couple doit atteindre la marge (1,5 ou 1,0), la vitesse 1,0. « — » : donnée non publiée (INCONNU).

| Axe | Requis : pointe, continu (N·m), vitesse (rad/s) | sts3215_c018 | sts3250 | HTD-85H | RSBL120-24 | KRS-9304HV ICS | DRS-0601 | LSS-HT1 | RS305CR | UBT-12HC (servo de l’Alpha 1S) | rs05 | edulite05 |
| --- | --- | --- | --- | --- | --- | --- | --- | --- | --- | --- | --- | --- |
| hip_pitch | 2,35, 0,70, 3,4 (marche) | 1,25 / 1,40 / 1,39 | 2,08 / 2,24 / 2,31 | 3,54 / — / 1,54 | 5,00 / — / 1,54 | 3,79 / — / 1,34 | 3,21 / — / 1,92 | 1,21 / 0,81 / 1,85 | 0,30 / — / 2,80 | 0,50 / — / 1,55 | 2,34 / 2,28 / 11,08 | 2,34 / 2,56 / 9,93 |
| hip_roll | 2,34, 0,94, 2,2 (marche) | 1,26 / 1,05 / 2,11 | 2,09 / 1,68 / 3,53 | 3,56 / — / 2,35 | 5,02 / — / 2,35 | 3,80 / — / 2,04 | 3,22 / — / 2,94 | 1,21 / 0,61 / 2,82 | 0,30 / — / 4,27 | 0,50 / — / 2,37 | 2,35 / 1,71 / 16,91 | 2,35 / 1,92 / 15,14 |
| hip_yaw | 1,12, 0,32, 2,5 (marche) | 2,63 / 3,09 / 1,89 | 4,38 / 4,95 / 3,15 | 7,44 / — / 2,10 | 10,51 / — / 2,10 | 7,96 / — / 1,82 | 6,74 / — / 2,62 | 2,54 / 1,79 / 2,52 | 0,62 / — / 3,81 | 1,05 / — / 2,12 | 4,91 / 5,04 / 15,10 | 4,91 / 5,67 / 13,52 |
| knee | 2,03, 0,52, 4,6 (marche) | 1,45 / 1,89 / 1,03 | 2,42 / 3,02 / 1,72 | 4,11 / — / 1,14 | 5,80 / — / 1,14 | 4,40 / — / 0,99 | 3,72 / — / 1,43 | 1,40 / 1,09 / 1,37 | 0,34 / — / 2,07 | 0,58 / — / 1,15 | 2,71 / 3,08 / 8,21 | 2,71 / 3,46 / 7,36 |
| ankle_pitch | 2,35, 0,99, 2,5 (marche) | 1,25 / 1,00 / 1,87 | 2,08 / 1,59 / 3,12 | 3,54 / — / 2,08 | 5,00 / — / 2,08 | 3,79 / — / 1,80 | 3,21 / — / 2,59 | 1,21 / 0,58 / 2,49 | 0,30 / — / 3,77 | 0,50 / — / 2,10 | 2,34 / 1,62 / 14,94 | 2,34 / 1,83 / 13,39 |

### Marges à 0,30 m/s (borne : Unitree G1 (0.547 m/s)) : couple de pointe / couple continu / vitesse

Chaque case : rapport « publié ÷ requis » ; le couple doit atteindre la marge (1,5 ou 1,0), la vitesse 1,0. « — » : donnée non publiée (INCONNU).

| Axe | Requis : pointe, continu (N·m), vitesse (rad/s) | sts3215_c018 | sts3250 | HTD-85H | RSBL120-24 | KRS-9304HV ICS | DRS-0601 | LSS-HT1 | RS305CR | UBT-12HC (servo de l’Alpha 1S) | rs05 | edulite05 |
| --- | --- | --- | --- | --- | --- | --- | --- | --- | --- | --- | --- | --- |
| hip_pitch | 2,72, 1,20, 5,7 (marche) | 1,08 / 0,82 / 0,83 | 1,80 / 1,31 / 1,38 | 3,06 / — / 0,92 | 4,33 / — / 0,92 | 3,28 / — / 0,80 | 2,78 / — / 1,15 | 1,05 / 0,47 / 1,10 | 0,26 / — / 1,67 | 0,43 / — / 0,93 | 2,02 / 1,34 / 6,62 | 2,02 / 1,50 / 5,93 |
| hip_roll | 1,72, 0,82, 4,4 (marche) | 1,71 / 1,19 / 1,06 | 2,84 / 1,91 / 1,78 | 4,83 / — / 1,18 | 6,82 / — / 1,18 | 5,17 / — / 1,03 | 4,38 / — / 1,48 | 1,65 / 0,69 / 1,42 | 0,40 / — / 2,15 | 0,68 / — / 1,19 | 3,19 / 1,94 / 8,50 | 3,19 / 2,19 / 7,61 |
| hip_yaw | 1,87, 0,71, 2,3 (marche) | 1,57 / 1,39 / 2,03 | 2,62 / 2,22 / 3,39 | 4,46 / — / 2,25 | 6,30 / — / 2,25 | 4,77 / — / 1,96 | 4,04 / — / 2,82 | 1,52 / 0,80 / 2,70 | 0,37 / — / 4,10 | 0,63 / — / 2,28 | 2,94 / 2,26 / 16,23 | 2,94 / 2,54 / 14,54 |
| knee | 2,90, 1,28, 14,1 (marche) | 1,01 / 0,76 / 0,33 | 1,69 / 1,22 / 0,56 | 2,87 / — / 0,37 | 4,06 / — / 0,37 | 3,07 / — / 0,32 | 2,60 / — / 0,46 | 0,98 / 0,44 / 0,45 | 0,24 / — / 0,67 | 0,41 / — / 0,37 | 1,90 / 1,25 / 2,67 | 1,90 / 1,40 / 2,39 |
| ankle_pitch | 1,11, 0,26, 18,2 (autres tâches) | 2,65 / 3,79 / 0,26 | 4,41 / 6,06 / 0,43 | 7,50 / — / 0,29 | 10,58 / — / 0,29 | 8,02 / — / 0,25 | 6,79 / — / 0,36 | 2,56 / 2,20 / 0,35 | 0,63 / — / 0,52 | 1,06 / — / 0,29 | 4,95 / 6,18 / 2,07 | 4,95 / 6,95 / 1,86 |

## Robot entier, règle plus_lente

**La règle « plus_lente » n'est PAS adoptée** : elle attend une fiche de décision de Jeremy (elle touche la fiche 0064). L'explorateur garde « explorateur » par défaut (`--regle-marche`, test de non-régression contre le commit cc340fd). Méthode et configurations imposées : en tête de `scripts/lab_leger_entier.py`.

| Config | Structure | Marge | Marche (m/s) | Plus petite H → réelle (m) | Masse (kg) | Coût (CHF) | Chute (J) | Autonomie (min) | Jambes | Axes les plus justes (pointe ÷ requis, continu ÷ requis, vitesse ÷ requise) | Kit réutilisé |
| --- | --- | ---: | ---: | --- | ---: | ---: | ---: | ---: | --- | --- | ---: |
| A | carton | 1,5 | 0,100 | **ne tient à aucune H** de 0,35 à 0,65 m | — | — | — | — | — | — | — |
| A | carton | 1,5 | 0,150 | **ne tient à aucune H** de 0,35 à 0,65 m | — | — | — | — | — | — | — |
| A | carton | 1,5 | 0,196 | **ne tient à aucune H** de 0,35 à 0,65 m | — | — | — | — | — | — | — |
| A | carton | 1,0 | 0,100 | 0,45 → 0,826 | 3,5 | ≥ 1 904 | 16 | 59 | sts3250 | knee sts3250 (3,16, 3,94, 1,49); shoulder_pitch sts3215_c018 (14,30, —, 1,92) | 70 % |
| A | carton | 1,0 | 0,150 | 0,45 → 0,826 | 3,5 | ≥ 1 904 | 16 | 59 | sts3250 | knee sts3250 (3,16, 3,94, 1,49); shoulder_pitch sts3215_c018 (14,30, —, 1,92) | 70 % |
| A | carton | 1,0 | 0,196 | 0,65 → 0,689 | 3,6 | ≥ 1 904 | 14 | 56 | sts3250 | ankle_pitch sts3250 (1,84, 1,41, 3,25); hip_roll sts3250 (1,85, 1,49, 3,68) | 70 % |
| A | alu 2 mm évidé | 1,5 | 0,100 | **ne tient à aucune H** de 0,35 à 0,65 m | — | — | — | — | — | — | — |
| A | alu 2 mm évidé | 1,5 | 0,150 | **ne tient à aucune H** de 0,35 à 0,65 m | — | — | — | — | — | — | — |
| A | alu 2 mm évidé | 1,5 | 0,196 | **ne tient à aucune H** de 0,35 à 0,65 m | — | — | — | — | — | — | — |
| A | alu 2 mm évidé | 1,0 | 0,100 | **ne tient à aucune H** de 0,35 à 0,65 m | — | — | — | — | — | — | — |
| A | alu 2 mm évidé | 1,0 | 0,150 | **ne tient à aucune H** de 0,35 à 0,65 m | — | — | — | — | — | — | — |
| A | alu 2 mm évidé | 1,0 | 0,196 | **ne tient à aucune H** de 0,35 à 0,65 m | — | — | — | — | — | — | — |
| B | alu 2 mm évidé | 1,5 | 0,100 | **ne tient à aucune H** de 0,35 à 0,65 m | — | — | — | — | — | — | — |
| B | alu 2 mm évidé | 1,5 | 0,150 | **ne tient à aucune H** de 0,35 à 0,65 m | — | — | — | — | — | — | — |
| B | alu 2 mm évidé | 1,5 | 0,196 | **ne tient à aucune H** de 0,35 à 0,65 m | — | — | — | — | — | — | — |
| B | alu 2 mm évidé | 1,0 | 0,100 | **ne tient à aucune H** de 0,35 à 0,65 m | — | — | — | — | — | — | — |
| B | alu 2 mm évidé | 1,0 | 0,150 | **ne tient à aucune H** de 0,35 à 0,65 m | — | — | — | — | — | — | — |
| B | alu 2 mm évidé | 1,0 | 0,196 | **ne tient à aucune H** de 0,35 à 0,65 m | — | — | — | — | — | — | — |
| B | carton | 1,5 | 0,100 | **ne tient à aucune H** de 0,35 à 0,65 m | — | — | — | — | — | — | — |
| B | carton | 1,5 | 0,150 | **ne tient à aucune H** de 0,35 à 0,65 m | — | — | — | — | — | — | — |
| B | carton | 1,5 | 0,196 | **ne tient à aucune H** de 0,35 à 0,65 m | — | — | — | — | — | — | — |
| B | carton | 1,0 | 0,100 | 0,55 → — | 5,5 | ≥ 2 332 | — | 230 | edulite05, rs05 | ankle_pitch edulite05 (1,60, 1,25, 12,82); hip_roll edulite05 (1,61, 1,32, 14,50) | 70 % |
| B | carton | 1,0 | 0,150 | 0,55 → — | 5,5 | ≥ 2 332 | — | 230 | edulite05, rs05 | ankle_pitch edulite05 (1,60, 1,25, 12,82); hip_roll edulite05 (1,61, 1,32, 14,50) | 70 % |
| B | carton | 1,0 | 0,196 | 0,65 → — | 5,6 | ≥ 2 353 | — | 221 | edulite05, rs05 | ankle_pitch edulite05 (1,33, 1,04, 13,93); hip_roll edulite05 (1,33, 1,09, 15,76) | 71 % |

Lecture : « — » en hauteur réelle (configuration B) : les cotes de l'EduLite05 ne sont pas publiées, la place (taille minimale géométrique) ne se calcule pas ; l'énergie de chute, qui en dépend, non plus. À 0,196 m/s, la plus petite H est plus grande qu'à 0,15 : sous H ≈ 0,60 m, la marche ToddlerBot mise à l'échelle va moins vite que 0,196 m/s, et la règle passe alors au G1 (0,55 m/s à 0,60 m), bien plus exigeant. Une hauteur réelle très supérieure à H (0,45 → 0,826 m) vient de la place : les servos ne tiennent pas dans les proportions ANSUR d'un robot de 0,45 m, les chaînes s'allongent.

### Ce que la règle changerait ailleurs (documents NON régénérés)

| Profil | Règle « explorateur » (en vigueur) | Règle « plus_lente » |
| --- | --- | --- |
| Lab actuel, en « Home candidat » (ensemble 27, RobStride + Feetech, 12S, plus petite H) | H 0,85 → 0,850 m, 18,5 kg, ≥ 4 514 CHF, INCONNU | H 0,85 → 0,850 m, 18,5 kg, ≥ 4 514 CHF, INCONNU |
| Kit, option progressive | 3,05 kg, 1 178 CHF, servos sts3215_c018, sts3250 | 3,05 kg, 1 178 CHF, servos sts3215_c018, sts3250 |

## Le Lab actuel, recalculé comme « Home candidat » (rien n'est changé)

Profil lab, 12S, 250 Hz, chaîne compacte, ensemble 27, H = 0,85 m, petits axes Feetech : **INCONNU**, 0,850 m réels, 18,5 kg, ≥ 4 514 CHF, énergie de chute 87 J.

## Parmi les repères publiés (au registre ou dans les rapports)

| Robot | Hauteur (m) | Masse (kg) | Actionneurs | Coût | Marche démontrée | Source |
| --- | ---: | ---: | --- | --- | --- | --- |
| ToddlerBot 2XC | 0,56 | 3,4 | Dynamixel (6 axes par jambe) | — | oui (politique publiée, rejouée ici) | references_simulables.yaml |
| Zeroth-01 | 0,40 | 2,0 | STS3250 (5 axes par jambe) | — | non vue | docs/dimensionnement-par-actionneur.md (~0,40 m et ~2 kg, non vérifiés) |
| Berkeley Humanoid Lite | 0,80 | 16,0 | actionneurs maison (6 axes par jambe) | — | oui (politique publiée) | references_simulables.yaml |
| LeRobot Humanoid | — | 19,4 | RobStride RS00, RS02, RS03, RS05 (6 axes par jambe) | < 5 000 USD (objectif) | oui (politiques publiées) | references_simulables.yaml |

**Absents du registre et des rapports** (non placés, aucune recherche dans ce lot court) : Open Duck Mini v2, BRIDGE, Bumi.

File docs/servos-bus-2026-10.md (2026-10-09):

# Les familles de petits servos à bus (2026-10)

**Engendré** par `.venv/bin/python scripts/servos_bus.py --ecrire`. **Étude, AUCUNE décision, aucun achat.** Question de Jeremy (2026-10-08) : « Pourquoi choisir du Feetech ? Car ce sont les actionneurs les moins chers du marché ? » Méthode et limites : en tête de `scripts/servos_bus.py`.

## Par famille

Couple : AU BLOCAGE (le seul publié partout) ; vitesse à vide à la tension de la fiche ; prix en CHF HT. « Continu publié » : nombre de modèles dont le fabricant publie un couple continu ou nominal.

| Famille | Modèles | N·m par 100 g (meilleur) | N·m par 10 CHF (meilleur) | Le plus fort (N·m) | Le plus rapide (rad/s) | Prix le plus bas (CHF) | Continu publié | Sans prix CHF | Retours de fiabilité | Robots qui marchent (relevés) |
| --- | ---: | ---: | ---: | ---: | ---: | ---: | ---: | ---: | ---: | --- |
| Hiwonder | 6 | 6,90 | 2,50 | 8,34 | 5,8 | 14 | 0/6 | 0 | 2 | Walbi, the Walking Biped |
| Waveshare | 6 | — | 1,54 | 11,77 | 10,5 | 8 | 0/6 | 1 | 1 | Chien robot 12 DDL (modèle ouvert Waveshare) |
| Kondo | 6 | 8,18 | — | 8,91 | 9,5 | — | 0/6 | 6 | — | — |
| HerkuleX | 4 | 6,14 | 0,23 | 7,55 | 7,1 | 51 | 2/4 | 2 | 1 | — |
| Lynxmotion LSS | 3 | 4,51 | — | 2,84 | 10,5 | — | 3/3 | 3 | — | SES-V2 Hexapod (18 × LSS-ST1) et mechDOG (quadrupède, LSS-ST1) |
| Futaba RS (commande) | 5 | 2,84 | — | 0,70 | 9,5 | — | 0/5 | 5 | — | — |
| UBTECH | 1 | 2,80 | — | 1,18 | 5,3 | — | 0/1 | 1 | — | — |
| Feetech | 16 | 6,58 | 1,40 | 4,90 | 20,9 | 10 | 16/16 | 11 | — | — |
| Dynamixel | 16 | 5,00 | 0,49 | 4,10 | 40,1 | 28 | 0/16 | 0 | — | — |

Retours de fiabilité et robots : relevés par l'agent (`params/servos_bus.yaml`, `familles`) pour les familles nouvelles ; pour Feetech et Dynamixel, non relevés dans ce lot (« — » ne veut pas dire « aucun »).

## Le Lab léger tiendrait-il avec une autre famille ? (marge 1,5, H = 0,60 m, 3,45 kg)

| Axe | Pointe requise × 1,5 (N·m) | Continu requis × 1,5 (N·m) | Vitesse requise (rad/s) |
| --- | ---: | ---: | ---: |
| hip_pitch | 4,08 | 1,80 | 6,0 |
| hip_roll | 2,59 | 1,26 | 4,4 |
| hip_yaw | 2,80 | 1,06 | 4,6 |
| knee | 4,35 | 1,92 | 14,1 |
| ankle_pitch | 1,67 | 0,43 | 18,2 |

| Famille | hip_pitch | hip_roll | hip_yaw | knee | ankle_pitch | Tient tout ? |
| --- | --- | --- | --- | --- | --- | --- |
| Hiwonder | non (vitesse) | oui (HTD-35H) | oui (HTD-35H) | non (vitesse) | non (vitesse) | **non** |
| Waveshare | non (vitesse) | oui (ST3215 (12 V)) | oui (ST3215 (12 V)) | non (vitesse) | non (vitesse) | **non** |
| Kondo | oui (KRS-4034HV ICS) | oui (KRS-4034HV ICS) | oui (KRS-4034HV ICS) | non (vitesse) | non (vitesse) | **non** |
| HerkuleX | oui (DRS-0401) | oui (DRS-0401) | oui (DRS-0401) | non (vitesse) | non (vitesse) | **non** |
| Lynxmotion LSS | non (couple) | non (couple) | non (couple) | non (ni couple ni vitesse) | non (vitesse) | **non** |
| Futaba RS (commande) | non (couple) | non (couple) | non (couple) | non (ni couple ni vitesse) | non (ni couple ni vitesse) | **non** |
| UBTECH | non (ni couple ni vitesse) | non (couple) | non (couple) | non (ni couple ni vitesse) | non (ni couple ni vitesse) | **non** |
| Feetech | non (couple) | oui (sts3250) | oui (sts3250) | non (vitesse) | non (vitesse) | **non** |
| Dynamixel | non (vitesse) | oui (xm430_w210) | oui (xm430_w210) | non (couple) | non (vitesse) | **non** |

« non (vitesse) » : des modèles ont le couple, aucun d'eux la vitesse ; « non (couple) » : le couple manque.

## Et à la marge 1,0 (repère : celle d'un robot qui marche déjà)

Familles qui tiendraient tous les axes de jambe : **aucune**. Feetech : hip_pitch oui (sts3250), hip_roll oui (sts3215_c018), hip_yaw oui (sts3215_c018), knee non (vitesse), ankle_pitch non (vitesse).

**Correction de docs/lab-leger-2026-10.md** (non régénéré : pas de relance de l'explorateur dans ce lot). Son seul résultat positif, « Feetech en carton tient à la marge 1,0 », reposait sur la vitesse INCONNUE du STS3250 dans le catalogue de l'explorateur (une donnée manquante ne fait pas échouer un choix). Avec la vitesse de sa fiche candidate (0,133 s/60°, soit 7,9 rad/s à 12 V, `params/actionneurs.yaml`), le genou (14 rad/s) et la cheville (18 rad/s) ne tiennent pas : ce résultat ne vaut pas.

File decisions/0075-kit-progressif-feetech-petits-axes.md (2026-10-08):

# 0075 — YXOR Kit progressif, debout en Feetech ; Feetech aux petits axes de toute la gamme

Date : 2026-10-08
État : acceptée
Complète : `0074-kit-modules-successifs.md` (dont elle tranche les niveaux,
l'option d'alimentation, le critère de recyclage et l'assemblage) et
touche `0069-deux-robots-lab-et-final.md` / `0073-gamme-yxor.md` : la
famille des petits axes devient commune à toute la gamme.

Décision coûteuse à inverser (règle 5) : elle fixe ce que l'utilisateur
achète à chaque niveau du Kit, et elle **impose une famille d'actionneurs
au Lab, au Home et au Pro** (cou, pinces), donc une interface (bus série
Feetech, adaptateur, fixations) partagée par toute la gamme.

## Décision

**DÉCIDÉE par Jeremy le 2026-10-08.** Ses mots (réponse écrite du
2026-10-08, vers 19 h 55, à la question « lesquelles de ces décisions sont
les tiennes ? ») :

> « Pour YXOR Kit : les niveaux 0 à 4 avec le niveau 3 limité à tenir
> debout en Feetech, la marche étant le passage au Lab ; l'option
> progressive, où chaque composant du Lab n'est acheté qu'au niveau qui en
> a besoin, avec un bloc secteur 12 V aux niveaux 1 et 2 et la batterie au
> niveau 3 seulement, dans un boîtier ignifuge ; je garde le critère de
> recyclage ; assemblage B. Les servos Feetech sont la famille des petits
> axes de toute la gamme. »

- **Niveaux 0 à 4** du Kit (`params/capacites.yaml`, `profils.kit.modules`) :
  0 articulé, 1 animé, 2 interactif, **3 debout** (tenir debout, en
  Feetech), 4 passage au Lab. **La marche est le passage au Lab.**
- **Option progressive** : chaque composant du Lab n'est acheté qu'au
  niveau qui en a besoin ; **bloc secteur 12 V aux niveaux 1 et 2** ;
  **batterie au niveau 3 seulement, dans un boîtier ignifuge**.
- **Critère de recyclage gardé** (filière papier, mono-matière) : le
  carton plume reste éliminé.
- **Assemblage B** : tenons et encoches, colle chaude non porteuse
  seulement, pivots par vis traversante (`docs/kit-yxor.md`).
- **Feetech est la famille des petits axes de toute la gamme** (cou,
  pinces : `explorateur.PETITS_AXES`). L'explorateur ne choisit plus entre
  Feetech et Dynamixel pour ces axes.

## Conséquence pour le Lab

Sa meilleure solution du 2026-10-08 mettait le cou en Dynamixel. Le coût
de la contrainte (CHF, kg) est mesuré par l'explorateur relancé avec
Feetech seul ; il est dans le journal et `docs/kit-yxor.md`.

## Ce qui n'est PAS décidé

- **Le carton précis** : le prompt du 2026-10-08 fait dessiner le niveau 0
  en carton ondulé double de 3,5 mm (la valeur mesurée, premier du
  classement) ; ce n'est pas un choix écrit par Jeremy.
- Le bloc secteur, le boîtier ignifuge et les servos exacts : comparés,
  pas choisis ; aucun achat (fiche 0066).

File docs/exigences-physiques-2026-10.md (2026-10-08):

# Exigences physiques par tâche, niveau et taille (octobre 2026)

**Engendré** par `.venv/bin/python scripts/exigences_physiques.py --ecrire`. Ne pas éditer à la main. **Étude, aucune décision** (phase 3a de la stratégie de la fiche 0069). Capacités et niveaux : `params/capacites.yaml`, confirmés par Jeremy le 2026-10-05.

## 1 — Familles d'actionneurs : plages couvertes

Depuis `params/actionneurs.yaml` (`candidats` et `marche`). Pointe : la pointe publiée, à défaut le blocage. **Lab** : au moins un modèle entre 5 et 20 N·m ; **final** : au moins un modèle ≥ 60 N·m (≥ 120 entre parenthèses). Ces deux ordres de grandeur viennent du prompt (Lab : étude du 2026-10-04 ; final : « ordre de grandeur Unitree G1 », NON lu) : ils seront recalculés en phase 3b.

| Famille | Modèles | Pointe (N·m) | Continu publié (N·m) | Masse (g) | Prix (CHF HT) | Lab | Final ≥ 60 (≥ 120) | Sans pointe | Sans continu |
| --- | ---: | --- | --- | --- | --- | --- | --- | ---: | ---: |
| RobStride (corps) | 10 | 5.5 – 120 | 1.6 – 35 | 191 – 1.42e+03 | 66.8 – 242 (10) | oui | oui (oui) | 0 | 0 |
| Damiao (corps) | 28 | 0.45 – 400 | 0.18 – 100 | 150 – 2.7e+03 | 49.2 – 334 (10) | oui | oui (oui) | 0 | 0 |
| SteadyWin (corps) | 47 | 1.27 – 228 (46 au blocage) | 0.65 – 54 | 97 – 1.37e+03 | 81.5 – 268 (27) | oui | oui (oui) | 46 | 0 |
| CubeMars (corps) | 21 | 4.1 – 222 | 1.3 – 74 | 190 – 1.4e+03 | 113 – 948 (21) | oui | oui (oui) | 0 | 0 |
| MyActuator (corps) | 32 | 3 – 450 | 0.9 – 150 | 230 – 4.32e+03 | 284 – 1.33e+03 (8) | oui | oui (oui) | 0 | 0 |
| HighTorque (corps) | 14 | 10 – 60 (10 au blocage) | 2 – 20 | 237 – 850 | 158 – 283 (13) | oui | oui (non) | 10 | 0 |
| Encos (corps) | 20 | 12 – 380 | 3 – 120 | 162 – 3.16e+03 | 522 – 1.98e+03 (20) | oui | oui (oui) | 0 | 0 |
| Unitree (corps) | 6 | 0.6 – 140 (2 au blocage) | — | 19.5 – 1.74e+03 | 24.2 – 2.5e+03 (6) | non | oui (oui) | 2 | 6 |
| Feetech (petits axes) | 16 | 0.0686 – 4.9 (15 au blocage) | 0.0157 – 1.57 | 4.8 – 74.5 | 10.3 – 31.3 (5) | non | non (non) | 15 | 0 |

Familles du corps qui couvrent à la fois le Lab et le final (≥ 60 N·m) : **RobStride, Damiao, SteadyWin, CubeMars, MyActuator, HighTorque, Encos**.

**PROPOSITION** (Claude, non écrite dans une fiche) : remplacer l'invariant « une famille » de la 0069 par « **une famille corps + une famille petits axes** ». Aucune famille du corps ne descend aux couples des doigts, du visage ou d'un petit cou (≤ 1 N·m, quelques grammes) : seuls les servos de bus (Feetech, Dynamixel) y sont. Garder une seule famille obligerait à des actionneurs de corps surdimensionnés au bout des bras et dans la tête.

## 2 — Couple nécessaire selon H, par tâche et par articulation

Couple nécessaire selon H

Chaque résultat est rangé sous la forme **τ = a·M + b** (M : masse du robot ; `b` : la charge ou la force, indépendante du robot). Un profil de capacités se combine par le **maximum** par articulation, avec la vraie masse de chaque solution (`combiner()`), sans recalcul. Les courbes utilisent la masse de référence M(H) = 3,454 kg × (H/0,56)³ (ToddlerBot, décision 3) ; l'étude S du 2026-10-04 pesait 2,3 fois plus à 0,61 m : la part `a·M` s'en trouverait multipliée d'autant.

### Lois et hypothèses

- Longueurs : ratios ANSUR × H (bras de levier ∝ H). Masses : fractions de Winter × M, centre de masse au milieu de chaque segment. Masse de référence des courbes ∝ H³.
- Rendement : non appliqué ; les puissances sont mécaniques (à la sortie de l'actionneur).
- Saut : force M·g·(1 + h/d) pendant une course de poussée d, durée 2d/√(2gh) ; couples dans l'accroupi ; puissance = couple maximal × vitesse maximale (borne haute).
- `poussee_saut_frac` = (voir texte) : REMPLACÉE le 2026-10-08 : la course de poussée du saut se CALCULE depuis l'accroupi (tibia incliné, hanche à l'aplomb de la cheville), voir geometrie_saut ; elle valait 25 % de la hauteur de hanche, incohérente avec les angles (genou 130° pour 64 mm à 0,50 m). PROPOSÉ par Claude, à remplacer.
- `inclinaison_tibia_deg` = (voir texte) : accroupi du saut et du relevé : params/exigences_S.yaml (releve.inclinaison_tibia_deg). PROPOSÉ par Claude, à remplacer.
- `levier_cheville_frac` = 0.5 : au saut, la réaction du sol passe à mi-longueur du pied devant la cheville. PROPOSÉ par Claude, à remplacer.
- `extension_cheville_deg` = 20 : au saut, la cheville s'étend de 20° au-delà de l'angle d'accroupi. PROPOSÉ par Claude, à remplacer.
- `distance_charge_m` = 0.3 : charge lourde : à 30 cm du torse (niveau CONFIRMÉ par Jeremy le 2026-10-05). PROPOSÉ par Claude, à remplacer.
- `frottement` = 0.5 : coefficient de frottement pince/objet et pied/sol. PROPOSÉ par Claude, à remplacer.
- `levier_pince_frac` = 0.5 : levier du doigt de la pince = moitié de la longueur de main. PROPOSÉ par Claude, à remplacer.
- `acceleration_geste_s` = 0.2 : geste rapide : vitesse atteinte en 0,2 s. PROPOSÉ par Claude, à remplacer.
- `inclinaison_buste_deg` = 30 : buste incliné de 30° (roulis ou tangage). PROPOSÉ par Claude, à remplacer.
- `part_tronc_au_dessus_taille` = 0.5 : la moitié de la masse du tronc (Winter) est au-dessus de la taille. PROPOSÉ par Claude, à remplacer.
- `marge_avant_pied_frac` = 0.5 : équilibre : le centre de pression ne dépasse pas la moitié avant du pied. PROPOSÉ par Claude, à remplacer.

### Masses minimales imposées (équilibre, frottement)

| Tâche | Niveau | H = 0,60 m | H = 1,00 m | H = 1,40 m |
| --- | --- | ---: | ---: | ---: |
| charge lourde | 2 | 11.0 kg | 5.8 kg | 3.6 kg |
| charge lourde | 5 | 27.6 kg | 14.6 kg | 9.0 kg |
| charge lourde | 10 | 55.2 kg | 29.1 kg | 17.9 kg |
| poussee | 20 | 4.1 kg | 4.1 kg | 4.1 kg |
| poussee | 50 | 10.2 kg | 10.2 kg | 10.2 kg |
| poussee | 100 | 20.4 kg | 20.4 kg | 20.4 kg |

Charge lourde : le robot doit peser au moins m·(d/x − 1) pour que la charge ne le fasse pas basculer en avant (x : moitié avant du pied), **buste droit** : c'est une borne PESSIMISTE, car se pencher en arrière déplace le centre de gravité du robot et réduit cette masse (à chiffrer en simulation). Poussée : M ≥ F/(μ·g) pour ne pas glisser.

### Trois courbes clés (masse de référence)

| H (m) | M réf. (kg) | Genou, saut 30 cm (N·m) | Épaule, charge 10 kg (N·m) | Hanche, relevé (N·m) |
| ---: | ---: | ---: | ---: | ---: |
| 0.50 | 2.5 | 6.1 | 14.9 | 0.6 |
| 0.60 | 4.2 | 10.9 | 15.0 | 1.3 |
| 0.80 | 10.1 | 27.2 | 15.5 | 4.0 |
| 1.00 | 19.7 | 56.0 | 16.2 | 9.8 |
| 1.20 | 34.0 | 101.7 | 17.2 | 20.4 |
| 1.40 | 54.0 | 169.1 | 18.7 | 37.7 |

Non chiffré ici : marche, sol irrégulier, pente, course (simulation, phase 3b) ; mains à doigts et visage (un nombre d'actionneurs, pas un couple) ; lacet du buste et de la tête (inertie seulement).

## 3 — Références simulables (marche, course)

Depuis `params/references_simulables.yaml` (lu le 2026-10-05).

| Référence | Licence du modèle | Politique pré-entraînée téléchargeable | Faire tourner ici (CPU) | Entraîner |
| --- | --- | --- | --- | --- |
| ToddlerBot 2XC (Stanford) | MJCF et code MIT ; mécanique CC BY-NC-SA 4.0 | oui, marche (+ ramper, grimper, se relever) : model_best.onnx, déjà dans ~/upstream (ckpts.manifest.yaml) ; licence des poids non déclarée | oui, vérifié ici le 2026-09-28 (0,102 m/s) | GPU (MJX/JAX, 4096 env., 1e9 pas) ; durée non publiée |
| Booster T1 (Booster Robotics) | Apache-2.0 | oui, marche : t1_policy.onnx (Playground) ; T1.pt (booster_gym, SDK Booster) | oui (onnxruntime) | GPU : < 30 min sur 2 × RTX 4090 (papier Playground) ; booster_gym : Isaac Gym, CUDA |
| Unitree G1 | BSD-3-Clause | oui, marche : motion.pt (unitree_rl_gym, BSD-3), g1_policy.onnx (Playground), GR00T (licence NVIDIA, non lue en entier), Holosoma (sans licence déclarée) | oui | GPU : < 30 min sur 2 × RTX 4090 (Playground) ; unitree_rl_gym : Isaac Gym |
| Berkeley Humanoid Lite | modèle CC BY-SA 4.0 (réciproque) ; code MIT | oui, marche : policy_biped_50hz.onnx et 5 autres ; licence des poids indéterminée | oui (Intel N95 à 25 Hz sur le robot) | GPU (Isaac Gym / Lab) ; durée non publiée |
| LeRobot Humanoid (Hugging Face) | Apache-2.0 (dépôts hardware, model, runtime) ; dépôt de tête sans licence déclarée | oui, marche : 15 dossiers control/policy/*/policy.onnx (tâche mjlab de suivi de vitesse, lin_vel_x ∈ [−1, 1] m/s) ; sur le robot réel, le billet ne montre qu'une politique debout | oui (onnxruntime ; runtime prévu sur Raspberry Pi 5) | GPU (mjlab, MuJoCo Warp) ; durée non publiée |
| MuJoCo Playground (google-deepmind) | Apache-2.0 ; chaque robot garde sa licence Menagerie | oui, marche au joystick : T1, G1, Berkeley Humanoid (pas la Lite), Apollo ; pas de ToddlerBot | oui (scripts sur CPU) | GPU (JAX CUDA 12) : 15 à 30 min sur 2 × RTX 4090 |

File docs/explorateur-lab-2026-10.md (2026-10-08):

# Explorateur : YXOR Lab

**Engendré** par `.venv/bin/python scripts/explorateur.py --ecrire`. Ne pas éditer à la main. **Étude, aucune décision d'architecture** (phases 4a et 4a bis, fiche 0069).

## Loi de masse

DÉCIDÉE par Jeremy le 2026-10-07 (`params/lois_masse.yaml`, `retenue`) : Jeremy, 2026-10-07, réponse à la question de Claude (phase 4a) : « J'adopte la loi allométrique mesurée, avec son intervalle comme bande d'incertitude ; H³ reste en mémoire comme borne pessimiste. »

Une solution n'est **faisable** que si elle tient aux trois exposants b = 1,814, 1,995 et 2,176, chacun avec la structure centrale (« évidée 50 % + 2 mm ») ET haute (« pleine 3 mm ») : six cas. La masse est donnée au b central, structure centrale ; la bande couvre les six cas. H³ (b = 3) est rapporté comme borne pessimiste, sans filtrer.

## Profil cible

Profil **lab** de `params/capacites.yaml` : DÉCIDÉ par Jeremy le 2026-10-07 (ses mots y sont cités). Capacités voulues : marche_sol_plat 0.6, sol_irregulier 2, pente 5, releve depuis le dos et depuis le ventre, saut_vertical 5, gestes_pointage 2.0, saisie 0.2, poussee 20, buste lacet seul, tete 2, visage écran, autonomie 30, ia_embarquee + vision. Axes exigés au-delà du calcul (PROPOSÉ) : sol_irregulier → ankle_roll, mains_a_doigts → doigts.

| Ensemble | Ne couvre pas | Voulues non calculées (INCONNUES) |
| ---: | --- | --- |
| 25 | sol_irregulier | pente, visage |
| 26 | sol_irregulier | pente, visage |
| 27 | — | sol_irregulier, pente, visage |
| 29 | — | sol_irregulier, pente, visage |

## Entrées et hypothèses

- Besoins : tables a·M + b des phases 3a (`exigences_physiques`) et 3b (`simulations_marche`, référence prudente : par axe, le robot le plus exigeant parmi ceux dont la marche couvre le Froude). Par axe, le **maximum** des tâches du profil, à la vraie masse de la solution ; `verifier_maximum` l'a recontrôlé sur 233 solutions.
- Marge : 1,5 sur les couples (fiche 0051). La vitesse à vide doit couvrir la vitesse de pointe, sans marge.
- Structure : segment par segment (`scripts/structure_plaques.py`, reconstruction des études du 2026-10-03 et 04 : caissons, liaisons à 90°, boîtes, étalonnés sur la CAO), à 0,60 m, puis × (H / 0,60)^b. Par ensemble (kg, centrale / haute) : 25 : 1,82 / 3,86 ; 26 : 1,86 / 3,92 ; 27 : 1,90 / 4,00 ; 29 : 1,97 / 4,12. Charge utile 0,3 kg (PROPOSÉE, `exigences_S.yaml`).
- Régimes : charge, saisie, poussée, buste et tête au couple **continu** ; saut, relevé et gestes au couple de **pointe** ; la marche aux deux.
- Place : taille minimale géométrique (`scripts/taille_minimale.py`, reconstruction de l'étude du 2026-10-04), lecture AVEC ÉCARTS : les chaînes verticales qui débordent (jambe, tronc, cou et tête) s'allongent, la hauteur RÉELLE vaut H + dépassements ; la lecture ANSUR stricte est rapportée. **Couples à la hauteur réelle** (phase 4a ter) : lus au pas supérieur de la grille (5 cm, prudent) au-dessus de la hauteur réelle, structure à la hauteur réelle, masse minimale au pas inférieur ; itération (choix → place → hauteur) jusqu'à stabilité. Le robot allongé est traité comme un robot proportionné à sa hauteur réelle : centre de gravité et bras de levier y grandissent tous, ce qui majore les couples (prudent). Cheville à 2 axes : la meilleure des options (a), (b), (d).
- Un axe absent de l'ensemble est rigide. Coût = actionneurs seuls (CHF HT, taux BCE de `budget.yaml`). Énergie de chute = M·g·(hauteur de hanche ANSUR × hauteur réelle).
- Actionneurs sans aucun couple publié, écartés : 0.

| Ensemble | Axes | Source |
| ---: | ---: | --- |
| 25 | 25 | JAMAIS calculé le 2026-10-04 (seulement cité par le prompt d'alors) : le 26 sans roulis de taille |
| 26 | 26 | squelette v3 (params/squelette.yaml, fiche 0068 : 5 axes par jambe) |
| 27 | 27 | fiche 0069 (proposition de Claude) et étude du 2026-10-04 : jambes 6 × 2, taille 1, bras 5 × 2, pinces, cou 2 |
| 29 | 29 | étude du 2026-10-04 (« 29, bras 5 ») : le 27 avec la taille à 3 axes |

Familles du corps : robstride, damiao, steadywin, cubemars, myactuator, hightorque, encos, unitree ; petits axes (cou, pinces) : feetech. L'invariant « famille RobStride » de la fiche 0069 n'est PAS appliqué ici : l'explorateur montre ce qu'il coûte.

## Bilan

36864 solutions évaluées en 566 s : 0 faisables, 14300 infaisables, 22564 INCONNUES. Par famille du corps :

| Famille | Faisables | Infaisables | INCONNUES |
| --- | ---: | ---: | ---: |
| robstride | 0 | 1870 | 2738 |
| damiao | 0 | 252 | 4356 |
| steadywin | 0 | 3824 | 784 |
| cubemars | 0 | 190 | 4418 |
| myactuator | 0 | 2388 | 2220 |
| hightorque | 0 | 4608 | 0 |
| encos | 0 | 0 | 4608 |
| unitree | 0 | 1168 | 3440 |

## Front de Pareto

Front de Pareto

0 solutions non dominées (coût, masse, énergie de chute, capacités tenues, capacités voulues couvertes).

## Les 5 meilleures solutions

Classement PROPOSÉ : le moins de capacités voulues NON couvertes, puis le plus de capacités tenues, puis le moins cher, puis le plus léger, parmi le front. H = échelle des proportions ; « réelle » = avec les écarts.

| # | Ensemble | H → réelle (m) | Corps + petits | Masse (kg) [bande] | H³ (kg) | Coût (CHF) | Chute (J) | Capacités tenues | Ne couvre pas |
| ---: | ---: | --- | --- | --- | --- | ---: | ---: | --- | --- |

## Coût de chaque capacité

Pour chaque tâche calculée du profil, et chaque niveau jusqu'au niveau visé : la solution faisable la moins chère sur tout l'espace (ensembles, H, familles), avec la marche au niveau du profil ; l'écart est pris au niveau inférieur (au premier niveau : à la marche seule). « H min » = la plus petite hauteur RÉELLE où une solution est faisable.

**Lecture** : « le plus petit actionneur » est le plus LÉGER, pas le moins cher. Un niveau plus exigeant peut donc coûter MOINS (un actionneur plus lourd mais meilleur marché devient le plus petit qui passe) : un écart négatif n'est pas une erreur de calcul, c'est le prix de la légèreté.

| Tâche | Niveau | Coût (CHF) | + CHF | Masse (kg) | + kg | Hauteur réelle de la moins chère | H min réelle | Note |
| --- | --- | ---: | ---: | ---: | ---: | ---: | ---: | --- |
| marche seule (référence) | 0.6 | ≥ 4 019 | — | 10,2 | — | 0,722 | — | |
| marche_sol_plat | 0.3 | ≥ 4 019 | — | 10,2 | — | 0,722 | — | ≥ : chaîne de puissance incomplètement chiffrée |
| marche_sol_plat | 0.6 | ≥ 4 019 | +0 | 10,2 | +0,0 | 0,722 | — | ≥ : chaîne de puissance incomplètement chiffrée |
| releve | depuis le dos | ≥ 4 019 | +0 | 10,2 | +0,0 | 0,722 | — | ≥ : chaîne de puissance incomplètement chiffrée |
| releve | depuis le ventre | ≥ 4 019 | +0 | 10,2 | +0,0 | 0,722 | — | ≥ : chaîne de puissance incomplètement chiffrée |
| saut_vertical | 5 | ≥ 4 009 | −10 | 10,3 | +0,2 | 0,683 | — | ≥ : chaîne de puissance incomplètement chiffrée |
| gestes_pointage | 0.5 | ≥ 4 019 | +0 | 10,2 | +0,0 | 0,722 | — | ≥ : chaîne de puissance incomplètement chiffrée |
| gestes_pointage | 1.0 | ≥ 4 019 | +0 | 10,2 | +0,0 | 0,722 | — | ≥ : chaîne de puissance incomplètement chiffrée |
| gestes_pointage | 2.0 | ≥ 4 019 | +0 | 10,2 | +0,0 | 0,722 | — | ≥ : chaîne de puissance incomplètement chiffrée |
| saisie | 0.2 | ≥ 4 003 | −16 | 10,9 | +0,7 | 0,677 | — | ≥ : chaîne de puissance incomplètement chiffrée |
| poussee | 20 | ≥ 4 221 | +202 | 10,7 | +0,6 | 0,722 | — | ≥ : chaîne de puissance incomplètement chiffrée |
| buste | lacet seul | ≥ 4 019 | +0 | 10,2 | +0,0 | 0,722 | — | ≥ : chaîne de puissance incomplètement chiffrée |
| tete | 2 | ≥ 4 030 | +11 | 10,2 | +0,1 | 0,731 | — | ≥ : chaîne de puissance incomplètement chiffrée |

## Données INCONNUES les plus bloquantes

Rangées par le nombre de solutions INCONNUES où elles manquent ; « seule » = solutions qui deviendraient décidables avec cette seule donnée.

| Donnée manquante | Solutions | Seule |
| --- | ---: | ---: |
| masse de Maytech MTS2009AS anti-spark switch 300A 20-85V (anti_etincelle) | 22564 | 0 |
| courant de Maytech MTS2009AS anti-spark switch 300A 20-85V (anti_etincelle) | 22564 | 0 |
| prix de HPD Power Bleeding Module (regeneration) | 22564 | 0 |
| tension de HPD Power Bleeding Module (regeneration) | 22564 | 0 |
| masse de JBD SP17S005 smart BMS (variantes NMC 20 à 120 A) (bms_port_commun) | 19080 | 0 |
| port commun (régénération) de JBD SP17S005 smart BMS (variantes NMC 20 à 120 A) (bms_port_commun) | 19080 | 0 |
| courant de Victron porte-fusible MIDI (CIP000050001) (porte_fusible) | 16730 | 0 |
| tension de Victron porte-fusible MIDI (CIP000050001) (porte_fusible) | 16730 | 0 |
| prix de GIGAVAC P105 MiniTACTOR (contacteur_compact) | 12916 | 0 |
| masse de GIGAVAC P105 MiniTACTOR (contacteur_compact) | 12916 | 0 |
| cotes de GIGAVAC P105 MiniTACTOR (contacteur_compact) | 12916 | 0 |
| courant de GIGAVAC P105 MiniTACTOR (contacteur_compact) | 12916 | 0 |

Hors calcul pour toute solution (capacités jamais « tenues » ici) :

- **sol_irregulier** : simulation de marche sur obstacles de 2 et 4 cm : non faite
- **pente** : simulation de marche en pente de 5 et 10° : non faite
- **course** : aucune politique de course (phase 3b) : rien à mettre à l'échelle
- **mains_a_doigts** : aucun ensemble du Lab n'a de doigts
- **visage** : masse, prix et place d'un écran ou de micro-servos : non relevés
- **structure** : seule la jambe basse est dessinée ; les autres segments sont estimés par des formules étalonnées sur elle ; l'évidement est une borne haute ; l'alu 2 mm n'est pas confirmé chez l'opérateur.
- **place** : volume de l'électronique et de la batterie dans le tronc compté NUL ; cardan des bielles (b) supposé ; servos en boîtier pris dans leur plus grande cote.

## Système électrique : 12S, 250 / 500 Hz, tension de coupure en variante (phases 4a quinquies et sexies)

Contexte DÉCIDÉ : fiches 0070 (batterie), 0071 (Lab : autonomie 30 min sur le cycle 40 s de marche + 20 s debout, IA « commande + vision ») et 0072 (Jeremy, 2026-10-08 : « Je retiens le 12S pour les deux robots, sur les chiffres de l'explorateur du 7 octobre. »). La tension de COUPURE (seuil d'arrêt) est étudiée en variante : 2,5, 3,0 et 3,2 V par cellule. Tout le reste est PROPOSÉ (`params/puissance.yaml`) :

- puissance électrique = puissance mécanique MOYENNE de la marche simulée (phase 3b, |τ·ω|, le robot le plus exigeant qui couvre le Froude) ÷ rendement BAS 0,4 (bande 0,4–0,7), sur 40 s de 60 ; debout, puissance mécanique nulle et pertes de maintien NON comptées (sous-estimation, dite) ; plus le calculateur ;
- énergie = puissance moyenne × autonomie ÷ 0,9 (part utilisable) ; courant de pointe = Σ des pointes par axe (marche simulée et tâches directes du profil) ÷ rendement bas ÷ tension de COUPURE ;
- batterie : la composition S × P de cellules 21700 la plus LÉGÈRE du marché versé qui fournit l'énergie et dont le courant CONTINU publié tient la pointe ; masse × 1,3, volume des cylindres ÷ π/4 × 1,2 ;
- tension : chaque RobStride doit accepter le pack de la coupure à la pleine charge (plage publiée) ; sa vitesse à vide est ramenée à la tension de COUPURE, proportionnellement (hypothèse écrite ; fiche à 48 V) : ×0.625 à 2,5 V ; ×0.750 à 3,0 V ; ×0.800 à 3,2 V ; énergie au-dessus de la coupure : 2,5 V : 100 % ; 3,0 V : 85 % ; 3,2 V : 70 % de l'énergie nominale (PROPOSÉ, prudent : courbe de décharge non lue numériquement) ;
- calculateur : le moins cher qui convient au niveau d'IA (critères PROPOSÉS : commande seule : accélérateur non, ≥ 4 GB ; + vision : accélérateur oui, ≥ 4 GB ; + vision et voix : accélérateur oui, ≥ 8 GB ; + modèle de langage local : accélérateur oui, ≥ 16 GB, modèles de langage), carte porteuse comprise, alimenté par le rail 12 V (Raspberry Pi : 12 → 5 V) ;
- bus : canaux CAN au calcul écrit (`docs/marche-bus-2026-10.md`), au-delà de ceux du calculateur par l'adaptateur le moins cher à pilote Linux principal ; un adaptateur série Feetech ;
- chaîne de puissance et rails : `params/puissance.yaml` (cellules → fusible → sectionneur → BMS → contacteur → précharge → bus moteurs ; absorbeur de régénération ; arrêt d'urgence matériel ; rails 12, 7,4, 6 et 5 V). Masses et cotes non publiées : BORNES PROPOSÉES majorantes (`bornes_proposees`, justifiées une par une) ; une solution qui en use est marquée « bornes proposées », jamais « vérifiée » ;
- batterie : cellules NEUVES d'un distributeur identifié seulement (récupération, occasion, marque masquée écartées) ;
- place : batterie, calculateur, cartes et convertisseurs dans 50 % du tronc (largeur d'épaules × profondeur de poitrine × hauteur du tronc, ANSUR, à la hauteur réelle) ; ce qui dépasse ALLONGE le tronc (même lecture « avec écarts » que la place des moteurs).

**Référence, méthode de 14 h 05 recalculée (sans système électrique, charge utile forfaitaire de 1,2 kg)** : 27 axes, 0,50 → 0,550 m, 9,2 kg, 2 600 CHF (actionneurs seuls).

### Chaîne compacte et chaîne industrielle (meilleure solution RobStride)

| Fréquence | Chaîne | Volume électronique (L) | Masse (kg) | Coût TOTAL (CHF HT) | Hauteur réelle (m) | Rallonge du tronc (mm) | Batterie |
| ---: | --- | ---: | ---: | ---: | ---: | ---: | --- |
| 250 Hz | compacte | 2,82 (partiel) | 18,5 | ≥ 4 514 | 0,850 | 0 | INR-21700-P50B 12S2P, 420 Wh |
| 250 Hz | industrielle | 3,76 | 20,1 | ≥ 4 671 | 0,894 | 44 | INR-21700-P50B 12S2P, 420 Wh |
| 500 Hz | compacte | 3,03 (partiel) | 18,7 | ≥ 5 211 | 0,850 | 0 | INR-21700-P50B 12S2P, 420 Wh |
| 500 Hz | industrielle | 3,97 | 22,3 | ≥ 5 472 | 0,912 | 62 | INR-21700-P50B 12S2P, 420 Wh |

### Tension de coupure et tâches rapides (meilleure solution RobStride pour chaque tâche, marche au niveau du profil)

| Fréquence | Coupure (V/cellule) | saut 5 cm | saut 10 cm | gestes 2 m/s |
| ---: | ---: | --- | --- | --- |
| 250 Hz, chaîne compacte | 3,0 | tient : 25 axes, 0,649 m réels, 10,0 kg, ≥ 3 425 CHF | NE TIENT PAS (knee : aucun robstride ne tient (pointe #, continu # N·m, ω # rad/s, b bas, structure haut) | tient : 25 axes, 0,688 m réels, 10,0 kg, ≥ 3 555 CHF |
| 250 Hz, chaîne industrielle | 3,0 | tient : 25 axes, 0,900 m réels, 17,7 kg, ≥ 4 426 CHF | NE TIENT PAS (knee : aucun robstride ne tient (pointe #, continu # N·m, ω # rad/s, b bas, structure cent) | tient : 25 axes, 0,996 m réels, 13,5 kg, ≥ 4 063 CHF |
| 500 Hz, chaîne compacte | 3,0 | tient : 25 axes, 0,683 m réels, 10,3 kg, ≥ 4 009 CHF | NE TIENT PAS (knee : aucun robstride ne tient (pointe #, continu # N·m, ω # rad/s, b bas, structure haut) | tient : 25 axes, 0,722 m réels, 10,2 kg, ≥ 4 019 CHF |
| 500 Hz, chaîne industrielle | 3,0 | tient : 25 axes, 0,907 m réels, 17,9 kg, ≥ 4 890 CHF | NE TIENT PAS (knee : aucun robstride ne tient (pointe #, continu # N·m, ω # rad/s, b bas, structure cent) | tient : 25 axes, 1,024 m réels, 13,7 kg, ≥ 4 528 CHF |

### 12S, 250 Hz, coupure 3,0 V, chaîne compacte

36864 solutions : 0 faisables, 13414 infaisables, 23450 INCONNUES ; front de 0. Le front QUITTE la borne basse H = 0,50 m.

| Ensemble | H → réelle (m) | Corps + petits | Masse (kg) | Coût TOTAL (CHF HT) | dont actionneurs | Batterie | Calculateur | Canaux CAN | Statut |
| ---: | --- | --- | ---: | ---: | ---: | --- | --- | ---: | --- |
| 27 | 0,85 → 0,850 | robstride + feetech | 18,5 | ≥ 4 514 | — | INR-21700-P50B 12S2P, 420 Wh, 2,22 kg | Seeed reComputer Mini J3011 (Orin Nano 8 GB inclus) | 3 | INCONNU (bornes proposées) |
| 27 | 0,70 → 0,700 | encos + feetech | 11,8 | ≥ 13 778 | 12 695 | INR-21700-P42A 12S2P, 353 Wh, 2,18 kg | Seeed reComputer Mini J3011 (Orin Nano 8 GB inclus) | 3 | INCONNU (bornes proposées) |
| 27 | 0,75 → 0,750 | encos + feetech | 12,3 | ≥ 13 786 | 12 695 | INR-21700-P42A 12S2P, 353 Wh, 2,18 kg | Seeed reComputer Mini J3011 (Orin Nano 8 GB inclus) | 3 | INCONNU (bornes proposées) |
| 27 | 0,50 → 0,659 | encos + feetech | 9,5 | ≥ 13 831 | 12 716 | INR-21700-P50B 12S1P, 210 Wh, 1,11 kg | Seeed reComputer Mini J3011 (Orin Nano 8 GB inclus) | 3 | INCONNU (bornes proposées) |
| 27 | 0,55 → 0,632 | encos + feetech | 9,7 | ≥ 13 831 | 12 716 | INR-21700-P50B 12S1P, 210 Wh, 1,11 kg | Seeed reComputer Mini J3011 (Orin Nano 8 GB inclus) | 3 | INCONNU (bornes proposées) |

Meilleures solutions **RobStride** (famille des deux robots, fiche 0069), avec leurs capacités tenues :

| Ensemble | H → réelle (m) | Corps + petits | Masse (kg) | Coût TOTAL (CHF HT) | dont actionneurs | Batterie | Calculateur | Canaux CAN | Statut |
| ---: | --- | --- | ---: | ---: | ---: | --- | --- | ---: | --- |
| 27 | 0,85 → 0,850 | robstride + feetech | 18,5 | ≥ 4 514 | — | INR-21700-P50B 12S2P, 420 Wh, 2,22 kg | Seeed reComputer Mini J3011 (Orin Nano 8 GB inclus) | 3 | INCONNU (bornes proposées) |
| 27 | 0,60 → 0,728 | robstride + feetech | 12,9 | ≥ 3 949 | 2 857 | INR-21700-P42A 12S2P, 353 Wh, 2,18 kg | Seeed reComputer Mini J3011 (Orin Nano 8 GB inclus) | 3 | INCONNU (bornes proposées) |
| 27 | 0,55 → 0,664 | robstride + feetech | 11,5 | ≥ 3 955 | 2 857 | INR-21700-P42A 12S1P, 176 Wh, 1,09 kg | Seeed reComputer Mini J3011 (Orin Nano 8 GB inclus) | 3 | INCONNU (bornes proposées) |

- RobStride n° 1 : marche_sol_plat, releve, saut_vertical, gestes_pointage, saisie, poussee, buste, tete ; manque du profil : sol_irregulier, pente, visage
- RobStride n° 2 : marche_sol_plat, releve, saut_vertical, gestes_pointage, saisie, buste, tete ; manque du profil : sol_irregulier, pente, poussee, visage
- RobStride n° 3 : marche_sol_plat, releve, gestes_pointage, saisie, poussee, buste, tete ; manque du profil : sol_irregulier, pente, saut_vertical, visage

Volume électronique de la meilleure RobStride (27 axes, H 0,85) : 2,82 L requis pour 3,21 L disponibles (volume partiel : des cotes manquent) ; le tronc s'allonge de 0 mm.

| Élément | Volume (L) | Part |
| --- | ---: | ---: |
| bms : JK Smart Active Balance BMS B2A20S20P-HC | 0,968 | 34 % |
| batterie | 0,938 | 33 % |
| calculateur | 0,251 | 9 % |
| fusible : MEGA-Fuse fuse holder (porte-fusible MEG | 0,247 | 9 % |
| anti_etincelle : Maytech MTS2009AS anti-spark switch 300A | 0,136 | 5 % |
| arret_urgence : XA1E-BV302R, arrêt d'urgence Ø 16 mm, 2  | 0,096 | 3 % |
| cartes CAN | 0,071 | 3 % |
| regeneration : HPD Power Bleeding Module | 0,061 | 2 % |
| fusible_compact : Littelfuse MEGA 70 V High Performance SF | 0,021 | 1 % |
| dcdc : D42V110F12 (12V, 9A Step-Down Voltage Re | 0,012 | 0 % |
| dcdc : D42V110F6 (6V, 11A Step-Down Voltage Reg | 0,012 | 0 % |
| contacteur_compact : GIGAVAC P105 MiniTACTOR | — | 0 % |

Coût de chaque niveau d'autonomie et d'IA, pour la meilleure solution RobStride (27 axes, H 0,85, robstride + feetech, même profil) :

| Tâche | Niveau | Masse (kg) | Coût TOTAL (CHF HT) | Batterie | Calculateur | Hauteur réelle (m) | Statut |
| --- | --- | ---: | ---: | --- | --- | ---: | --- |
| autonomie | 10 | 18,5 | ≥ 4 514 | 12S2P 420 Wh | Seeed reComputer Mini J3011 (Orin Nano 8 GB inclus) | 0,850 | INCONNU |
| autonomie | 20 | 18,5 | ≥ 4 514 | 12S2P 420 Wh | Seeed reComputer Mini J3011 (Orin Nano 8 GB inclus) | 0,850 | INCONNU |
| autonomie | 30 | 18,5 | ≥ 4 514 | 12S2P 420 Wh | Seeed reComputer Mini J3011 (Orin Nano 8 GB inclus) | 0,850 | INCONNU |
| autonomie | 60 | 18,5 | ≥ 4 514 | 12S2P 420 Wh | Seeed reComputer Mini J3011 (Orin Nano 8 GB inclus) | 0,850 | INCONNU |
| ia_embarquee | commande seule | 18,5 | ≥ 4 514 | 12S2P 420 Wh | Seeed reComputer Mini J3011 (Orin Nano 8 GB inclus) | 0,850 | INCONNU |
| ia_embarquee | + vision | 18,5 | ≥ 4 514 | 12S2P 420 Wh | Seeed reComputer Mini J3011 (Orin Nano 8 GB inclus) | 0,850 | INCONNU |
| ia_embarquee | + vision et voix | 18,5 | ≥ 4 514 | 12S2P 420 Wh | Seeed reComputer Mini J3011 (Orin Nano 8 GB inclus) | 0,850 | INCONNU |
| ia_embarquee | + modèle de langage local | 18,1 | ≥ 4 359 | 12S2P 420 Wh | Raspberry Pi 5 16GB + Raspberry Pi AI HAT+ 2 | 0,850 | INCONNU |

### 12S, 250 Hz, coupure 3,0 V, chaîne industrielle

36864 solutions : 0 faisables, 17586 infaisables, 19278 INCONNUES ; front de 0. Le front QUITTE la borne basse H = 0,50 m.

| Ensemble | H → réelle (m) | Corps + petits | Masse (kg) | Coût TOTAL (CHF HT) | dont actionneurs | Batterie | Calculateur | Canaux CAN | Statut |
| ---: | --- | --- | ---: | ---: | ---: | --- | --- | ---: | --- |
| 27 | 0,50 → 1,235 | cubemars + feetech | 17,9 | ≥ 10 315 | 8 910 | INR-21700-P50B 12S2P, 420 Wh, 2,22 kg | Seeed reComputer Mini J3011 (Orin Nano 8 GB inclus) | 3 | INCONNU (bornes proposées) |
| 27 | 0,55 → 1,108 | cubemars + feetech | 18,0 | ≥ 10 315 | 8 910 | INR-21700-P50B 12S2P, 420 Wh, 2,22 kg | Seeed reComputer Mini J3011 (Orin Nano 8 GB inclus) | 3 | INCONNU (bornes proposées) |
| 29 | 0,50 → 1,235 | cubemars + feetech | 18,4 | ≥ 10 580 | 9 176 | INR-21700-P50B 12S2P, 420 Wh, 2,22 kg | Seeed reComputer Mini J3011 (Orin Nano 8 GB inclus) | 3 | INCONNU (bornes proposées) |
| 29 | 0,55 → 1,108 | cubemars + feetech | 18,6 | ≥ 10 584 | 9 179 | INR-21700-P50B 12S2P, 420 Wh, 2,22 kg | Seeed reComputer Mini J3011 (Orin Nano 8 GB inclus) | 3 | INCONNU (bornes proposées) |
| 27 | 0,70 → 0,936 | encos + feetech | 14,0 | ≥ 17 346 | 16 076 | INR-21700-P42A 12S2P, 353 Wh, 2,18 kg | Seeed reComputer Mini J3011 (Orin Nano 8 GB inclus) | 3 | INCONNU (bornes proposées) |

Meilleures solutions **RobStride** (famille des deux robots, fiche 0069), avec leurs capacités tenues :

| Ensemble | H → réelle (m) | Corps + petits | Masse (kg) | Coût TOTAL (CHF HT) | dont actionneurs | Batterie | Calculateur | Canaux CAN | Statut |
| ---: | --- | --- | ---: | ---: | ---: | --- | --- | ---: | --- |
| 27 | 0,85 → 0,894 | robstride + feetech | 20,1 | ≥ 4 671 | 3 266 | INR-21700-P50B 12S2P, 420 Wh, 2,22 kg | Seeed reComputer Mini J3011 (Orin Nano 8 GB inclus) | 3 | INCONNU (bornes proposées) |
| 27 | 0,90 → 0,900 | robstride + feetech | 22,4 | ≥ 4 775 | 3 370 | INR-21700-P50B 12S2P, 420 Wh, 2,22 kg | Seeed reComputer Mini J3011 (Orin Nano 8 GB inclus) | 3 | INCONNU (bornes proposées) |
| 29 | 0,90 → 1,009 | robstride + feetech | 25,2 | ≥ 4 848 | 3 543 | INR-21700-P42A 12S3P, 529 Wh, 3,28 kg | Seeed reComputer Mini J3011 (Orin Nano 8 GB inclus) | 3 | INCONNU (bornes proposées) |

- RobStride n° 1 : marche_sol_plat, releve, saut_vertical, gestes_pointage, saisie, poussee, buste ; manque du profil : sol_irregulier, pente, tete, visage
- RobStride n° 2 : marche_sol_plat, releve, saut_vertical, gestes_pointage, saisie, poussee, buste ; manque du profil : sol_irregulier, pente, tete, visage
- RobStride n° 3 : marche_sol_plat, releve, saut_vertical, gestes_pointage, saisie, poussee, buste ; manque du profil : sol_irregulier, pente, tete, visage

Volume électronique de la meilleure RobStride (27 axes, H 0,85) : 3,76 L requis pour 3,21 L disponibles ; le tronc s'allonge de 44 mm.

| Élément | Volume (L) | Part |
| --- | ---: | ---: |
| bms : JK Smart Active Balance BMS B2A20S20P-HC | 0,968 | 26 % |
| batterie | 0,938 | 25 % |
| contacteur : GV200PA, bobine 12 V | 0,562 | 15 % |
| sectionneur : Battery switch ON/OFF 275A | 0,369 | 10 % |
| calculateur | 0,251 | 7 % |
| fusible : MEGA-Fuse fuse holder (porte-fusible MEG | 0,247 | 7 % |
| precharge : Anti-spark Switch Smart V4.0 (300 A) | 0,149 | 4 % |
| arret_urgence : XA1E-BV302R, arrêt d'urgence Ø 16 mm, 2  | 0,096 | 3 % |
| cartes CAN | 0,071 | 2 % |
| regeneration : HPD Power Bleeding Module | 0,061 | 2 % |
| fusible : MEGA-fuse 58V/48V (125, 200, 225, 300 A) | 0,017 | 0 % |
| dcdc : D42V110F12 (12V, 9A Step-Down Voltage Re | 0,012 | 0 % |
| dcdc : D42V110F6 (6V, 11A Step-Down Voltage Reg | 0,012 | 0 % |

Coût de chaque niveau d'autonomie et d'IA, pour la meilleure solution RobStride (27 axes, H 0,85, robstride + feetech, même profil) :

| Tâche | Niveau | Masse (kg) | Coût TOTAL (CHF HT) | Batterie | Calculateur | Hauteur réelle (m) | Statut |
| --- | --- | ---: | ---: | --- | --- | ---: | --- |
| autonomie | 10 | 20,1 | ≥ 4 671 | 12S2P 420 Wh | Seeed reComputer Mini J3011 (Orin Nano 8 GB inclus) | 0,894 | INCONNU |
| autonomie | 20 | 20,1 | ≥ 4 671 | 12S2P 420 Wh | Seeed reComputer Mini J3011 (Orin Nano 8 GB inclus) | 0,894 | INCONNU |
| autonomie | 30 | 20,1 | ≥ 4 671 | 12S2P 420 Wh | Seeed reComputer Mini J3011 (Orin Nano 8 GB inclus) | 0,894 | INCONNU |
| autonomie | 60 | 20,1 | ≥ 4 671 | 12S2P 420 Wh | Seeed reComputer Mini J3011 (Orin Nano 8 GB inclus) | 0,894 | INCONNU |
| ia_embarquee | commande seule | 20,1 | ≥ 4 671 | 12S2P 420 Wh | Seeed reComputer Mini J3011 (Orin Nano 8 GB inclus) | 0,894 | INCONNU |
| ia_embarquee | + vision | 20,1 | ≥ 4 671 | 12S2P 420 Wh | Seeed reComputer Mini J3011 (Orin Nano 8 GB inclus) | 0,894 | INCONNU |
| ia_embarquee | + vision et voix | 20,1 | ≥ 4 671 | 12S2P 420 Wh | Seeed reComputer Mini J3011 (Orin Nano 8 GB inclus) | 0,894 | INCONNU |
| ia_embarquee | + modèle de langage local | 19,2 | ≥ 4 491 | 12S2P 420 Wh | Raspberry Pi 5 16GB + Raspberry Pi AI HAT+ 2 | 0,869 | INCONNU |

### 12S, 500 Hz, coupure 3,0 V, chaîne compacte

36864 solutions : 0 faisables, 14300 infaisables, 22564 INCONNUES ; front de 0. Le front QUITTE la borne basse H = 0,50 m.

| Ensemble | H → réelle (m) | Corps + petits | Masse (kg) | Coût TOTAL (CHF HT) | dont actionneurs | Batterie | Calculateur | Canaux CAN | Statut |
| ---: | --- | --- | ---: | ---: | ---: | --- | --- | ---: | --- |
| 27 | 0,85 → 0,850 | robstride + feetech | 18,7 | ≥ 5 211 | — | INR-21700-P50B 12S2P, 420 Wh, 2,22 kg | Seeed reComputer Mini J3011 (Orin Nano 8 GB inclus) | 6 | INCONNU (bornes proposées) |
| 27 | 0,70 → 0,723 | encos + feetech | 12,1 | ≥ 14 474 | 12 695 | INR-21700-P42A 12S2P, 353 Wh, 2,18 kg | Seeed reComputer Mini J3011 (Orin Nano 8 GB inclus) | 6 | INCONNU (bornes proposées) |
| 27 | 0,75 → 0,750 | encos + feetech | 12,5 | ≥ 14 483 | 12 695 | INR-21700-P42A 12S2P, 353 Wh, 2,18 kg | Seeed reComputer Mini J3011 (Orin Nano 8 GB inclus) | 6 | INCONNU (bornes proposées) |
| 27 | 0,50 → 0,709 | encos + feetech | 9,8 | ≥ 14 528 | 12 716 | INR-21700-P50B 12S1P, 210 Wh, 1,11 kg | Seeed reComputer Mini J3011 (Orin Nano 8 GB inclus) | 6 | INCONNU (bornes proposées) |
| 27 | 0,55 → 0,673 | encos + feetech | 10,0 | ≥ 14 528 | 12 716 | INR-21700-P50B 12S1P, 210 Wh, 1,11 kg | Seeed reComputer Mini J3011 (Orin Nano 8 GB inclus) | 6 | INCONNU (bornes proposées) |

Meilleures solutions **RobStride** (famille des deux robots, fiche 0069), avec leurs capacités tenues :

| Ensemble | H → réelle (m) | Corps + petits | Masse (kg) | Coût TOTAL (CHF HT) | dont actionneurs | Batterie | Calculateur | Canaux CAN | Statut |
| ---: | --- | --- | ---: | ---: | ---: | --- | --- | ---: | --- |
| 27 | 0,85 → 0,850 | robstride + feetech | 18,7 | ≥ 5 211 | — | INR-21700-P50B 12S2P, 420 Wh, 2,22 kg | Seeed reComputer Mini J3011 (Orin Nano 8 GB inclus) | 6 | INCONNU (bornes proposées) |
| 27 | 0,70 → 0,700 | robstride + feetech | 13,0 | ≥ 4 861 | 3 067 | INR-21700-P42A 12S1P, 176 Wh, 1,09 kg | Seeed reComputer Mini J3011 (Orin Nano 8 GB inclus) | 6 | INCONNU (bornes proposées) |
| 27 | 0,55 → 0,705 | robstride + feetech | 12,1 | ≥ 4 881 | 3 088 | INR-21700-P42A 12S1P, 176 Wh, 1,09 kg | Seeed reComputer Mini J3011 (Orin Nano 8 GB inclus) | 6 | INCONNU (bornes proposées) |

- RobStride n° 1 : marche_sol_plat, releve, saut_vertical, gestes_pointage, saisie, poussee, buste, tete ; manque du profil : sol_irregulier, pente, visage
- RobStride n° 2 : marche_sol_plat, releve, gestes_pointage, saisie, poussee, buste, tete ; manque du profil : sol_irregulier, pente, saut_vertical, visage
- RobStride n° 3 : marche_sol_plat, releve, gestes_pointage, saisie, poussee, buste, tete ; manque du profil : sol_irregulier, pente, saut_vertical, visage

Volume électronique de la meilleure RobStride (27 axes, H 0,85) : 3,03 L requis pour 3,21 L disponibles (volume partiel : des cotes manquent) ; le tronc s'allonge de 0 mm.

| Élément | Volume (L) | Part |
| --- | ---: | ---: |
| bms : JK Smart Active Balance BMS B2A20S20P-HC | 0,968 | 32 % |
| batterie | 0,938 | 31 % |
| cartes CAN | 0,284 | 9 % |
| calculateur | 0,251 | 8 % |
| fusible : MEGA-Fuse fuse holder (porte-fusible MEG | 0,247 | 8 % |
| anti_etincelle : Maytech MTS2009AS anti-spark switch 300A | 0,136 | 4 % |
| arret_urgence : XA1E-BV302R, arrêt d'urgence Ø 16 mm, 2  | 0,096 | 3 % |
| regeneration : HPD Power Bleeding Module | 0,061 | 2 % |
| fusible_compact : Littelfuse MEGA 70 V High Performance SF | 0,021 | 1 % |
| dcdc : D42V110F12 (12V, 9A Step-Down Voltage Re | 0,012 | 0 % |
| dcdc : D42V110F6 (6V, 11A Step-Down Voltage Reg | 0,012 | 0 % |
| contacteur_compact : GIGAVAC P105 MiniTACTOR | — | 0 % |

Coût de chaque niveau d'autonomie et d'IA, pour la meilleure solution RobStride (27 axes, H 0,85, robstride + feetech, même profil) :

| Tâche | Niveau | Masse (kg) | Coût TOTAL (CHF HT) | Batterie | Calculateur | Hauteur réelle (m) | Statut |
| --- | --- | ---: | ---: | --- | --- | ---: | --- |
| autonomie | 10 | 18,7 | ≥ 5 211 | 12S2P 420 Wh | Seeed reComputer Mini J3011 (Orin Nano 8 GB inclus) | 0,850 | INCONNU |
| autonomie | 20 | 18,7 | ≥ 5 211 | 12S2P 420 Wh | Seeed reComputer Mini J3011 (Orin Nano 8 GB inclus) | 0,850 | INCONNU |
| autonomie | 30 | 18,7 | ≥ 5 211 | 12S2P 420 Wh | Seeed reComputer Mini J3011 (Orin Nano 8 GB inclus) | 0,850 | INCONNU |
| autonomie | 60 | 18,7 | ≥ 5 211 | 12S2P 420 Wh | Seeed reComputer Mini J3011 (Orin Nano 8 GB inclus) | 0,850 | INCONNU |
| ia_embarquee | commande seule | 18,7 | ≥ 5 211 | 12S2P 420 Wh | Seeed reComputer Mini J3011 (Orin Nano 8 GB inclus) | 0,850 | INCONNU |
| ia_embarquee | + vision | 18,7 | ≥ 5 211 | 12S2P 420 Wh | Seeed reComputer Mini J3011 (Orin Nano 8 GB inclus) | 0,850 | INCONNU |
| ia_embarquee | + vision et voix | 18,7 | ≥ 5 211 | 12S2P 420 Wh | Seeed reComputer Mini J3011 (Orin Nano 8 GB inclus) | 0,850 | INCONNU |
| ia_embarquee | + modèle de langage local | 18,2 | ≥ 4 398 | 12S2P 420 Wh | Raspberry Pi 5 16GB + Raspberry Pi AI HAT+ 2 | 0,850 | INCONNU |

### 12S, 500 Hz, coupure 3,0 V, chaîne industrielle

36864 solutions : 0 faisables, 18066 infaisables, 18798 INCONNUES ; front de 0. Le front QUITTE la borne basse H = 0,50 m.

| Ensemble | H → réelle (m) | Corps + petits | Masse (kg) | Coût TOTAL (CHF HT) | dont actionneurs | Batterie | Calculateur | Canaux CAN | Statut |
| ---: | --- | --- | ---: | ---: | ---: | --- | --- | ---: | --- |
| 27 | 0,50 → 1,284 | cubemars + feetech | 18,1 | ≥ 11 012 | 8 910 | INR-21700-P50B 12S2P, 420 Wh, 2,22 kg | Seeed reComputer Mini J3011 (Orin Nano 8 GB inclus) | 6 | INCONNU (bornes proposées) |
| 27 | 0,55 → 1,149 | cubemars + feetech | 18,3 | ≥ 11 012 | 8 910 | INR-21700-P50B 12S2P, 420 Wh, 2,22 kg | Seeed reComputer Mini J3011 (Orin Nano 8 GB inclus) | 6 | INCONNU (bornes proposées) |
| 29 | 0,50 → 1,284 | cubemars + feetech | 18,7 | ≥ 11 277 | 9 176 | INR-21700-P50B 12S2P, 420 Wh, 2,22 kg | Seeed reComputer Mini J3011 (Orin Nano 8 GB inclus) | 6 | INCONNU (bornes proposées) |
| 29 | 0,55 → 1,149 | cubemars + feetech | 18,9 | ≥ 11 281 | 9 179 | INR-21700-P50B 12S2P, 420 Wh, 2,22 kg | Seeed reComputer Mini J3011 (Orin Nano 8 GB inclus) | 6 | INCONNU (bornes proposées) |
| 27 | 0,70 → 0,961 | encos + feetech | 14,3 | ≥ 18 043 | 16 076 | INR-21700-P42A 12S2P, 353 Wh, 2,18 kg | Seeed reComputer Mini J3011 (Orin Nano 8 GB inclus) | 6 | INCONNU (bornes proposées) |

Meilleures solutions **RobStride** (famille des deux robots, fiche 0069), avec leurs capacités tenues :

| Ensemble | H → réelle (m) | Corps + petits | Masse (kg) | Coût TOTAL (CHF HT) | dont actionneurs | Batterie | Calculateur | Canaux CAN | Statut |
| ---: | --- | --- | ---: | ---: | ---: | --- | --- | ---: | --- |
| 27 | 0,85 → 0,912 | robstride + feetech | 22,3 | ≥ 5 472 | 3 370 | INR-21700-P50B 12S2P, 420 Wh, 2,22 kg | Seeed reComputer Mini J3011 (Orin Nano 8 GB inclus) | 6 | INCONNU (bornes proposées) |
| 27 | 0,90 → 0,912 | robstride + feetech | 22,7 | ≥ 5 472 | 3 370 | INR-21700-P50B 12S2P, 420 Wh, 2,22 kg | Seeed reComputer Mini J3011 (Orin Nano 8 GB inclus) | 6 | INCONNU (bornes proposées) |
| 29 | 0,85 → 0,974 | robstride + feetech | 25,0 | ≥ 5 544 | 3 543 | INR-21700-P42A 12S3P, 529 Wh, 3,28 kg | Seeed reComputer Mini J3011 (Orin Nano 8 GB inclus) | 6 | INCONNU (bornes proposées) |

- RobStride n° 1 : marche_sol_plat, releve, saut_vertical, gestes_pointage, saisie, poussee, buste ; manque du profil : sol_irregulier, pente, tete, visage
- RobStride n° 2 : marche_sol_plat, releve, saut_vertical, gestes_pointage, saisie, poussee, buste ; manque du profil : sol_irregulier, pente, tete, visage
- RobStride n° 3 : marche_sol_plat, releve, saut_vertical, gestes_pointage, saisie, poussee, buste ; manque du profil : sol_irregulier, pente, tete, visage

Volume électronique de la meilleure RobStride (27 axes, H 0,85) : 3,97 L requis pour 3,34 L disponibles ; le tronc s'allonge de 51 mm.

| Élément | Volume (L) | Part |
| --- | ---: | ---: |
| bms : JK Smart Active Balance BMS B2A20S20P-HC | 0,968 | 24 % |
| batterie | 0,938 | 24 % |
| contacteur : GV200PA, bobine 12 V | 0,562 | 14 % |
| sectionneur : Battery switch ON/OFF 275A | 0,369 | 9 % |
| cartes CAN | 0,284 | 7 % |
| calculateur | 0,251 | 6 % |
| fusible : MEGA-Fuse fuse holder (porte-fusible MEG | 0,247 | 6 % |
| precharge : Anti-spark Switch Smart V4.0 (300 A) | 0,149 | 4 % |
| arret_urgence : XA1E-BV302R, arrêt d'urgence Ø 16 mm, 2  | 0,096 | 2 % |
| regeneration : HPD Power Bleeding Module | 0,061 | 2 % |
| fusible : MEGA-fuse 58V/48V (125, 200, 225, 300 A) | 0,017 | 0 % |
| dcdc : D42V110F12 (12V, 9A Step-Down Voltage Re | 0,012 | 0 % |
| dcdc : D42V110F6 (6V, 11A Step-Down Voltage Reg | 0,012 | 0 % |

Coût de chaque niveau d'autonomie et d'IA, pour la meilleure solution RobStride (27 axes, H 0,85, robstride + feetech, même profil) :

| Tâche | Niveau | Masse (kg) | Coût TOTAL (CHF HT) | Batterie | Calculateur | Hauteur réelle (m) | Statut |
| --- | --- | ---: | ---: | --- | --- | ---: | --- |
| autonomie | 10 | 22,3 | ≥ 5 472 | 12S2P 420 Wh | Seeed reComputer Mini J3011 (Orin Nano 8 GB inclus) | 0,912 | INCONNU |
| autonomie | 20 | 22,3 | ≥ 5 472 | 12S2P 420 Wh | Seeed reComputer Mini J3011 (Orin Nano 8 GB inclus) | 0,912 | INCONNU |
| autonomie | 30 | 22,3 | ≥ 5 472 | 12S2P 420 Wh | Seeed reComputer Mini J3011 (Orin Nano 8 GB inclus) | 0,912 | INCONNU |
| autonomie | 60 | 22,3 | ≥ 5 472 | 12S2P 420 Wh | Seeed reComputer Mini J3011 (Orin Nano 8 GB inclus) | 0,912 | INCONNU |
| ia_embarquee | commande seule | 22,3 | ≥ 5 472 | 12S2P 420 Wh | Seeed reComputer Mini J3011 (Orin Nano 8 GB inclus) | 0,912 | INCONNU |
| ia_embarquee | + vision | 22,3 | ≥ 5 472 | 12S2P 420 Wh | Seeed reComputer Mini J3011 (Orin Nano 8 GB inclus) | 0,912 | INCONNU |
| ia_embarquee | + vision et voix | 22,3 | ≥ 5 472 | 12S2P 420 Wh | Seeed reComputer Mini J3011 (Orin Nano 8 GB inclus) | 0,912 | INCONNU |
| ia_embarquee | + modèle de langage local | 19,2 | ≥ 4 530 | 12S2P 420 Wh | Raspberry Pi 5 16GB + Raspberry Pi AI HAT+ 2 | 0,869 | INCONNU |

### Vitesse des RobStride à la tension de coupure

- 12S, coupure 3,0 V, chaîne compacte : le plus rapide des RobStride compatibles, rs05, tourne à 37,7 rad/s à la coupure ; le saut de 5 cm demande jusqu'à 26,2 rad/s à H = 0,50 m (borne haute : rampe linéaire). Il passe.
- 12S, coupure 3,0 V, chaîne industrielle : le plus rapide des RobStride compatibles, rs05, tourne à 37,7 rad/s à la coupure ; le saut de 5 cm demande jusqu'à 26,2 rad/s à H = 0,50 m (borne haute : rampe linéaire). Il passe.

Deux hypothèses rendent ce verrou prudent : la vitesse à vide prise à la tension de COUPURE (et non nominale), et la vitesse du saut en rampe linéaire. Elles sont écrites ; c'est à Jeremy de dire si l'une doit être assouplie.

### Canaux CAN (27 axes ; 23 sur CAN, le cou et les pinces étant en Feetech)

| Fréquence | Protocole | 27 axes | 23 axes |
| ---: | --- | ---: | ---: |
| 250 Hz | MIT (trame standard) | 3 | 3 |
| 250 Hz | privé (trame étendue) | 4 | 3 |
| 500 Hz | MIT (trame standard) | 6 | 5 |
| 500 Hz | privé (trame étendue) | 7 | 6 |

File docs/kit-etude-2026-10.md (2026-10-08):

# YXOR Kit : modules, masses, couples et réutilisation (2026-10)

**Engendré** par `.venv/bin/python scripts/kit.py --ecrire`. Ne pas éditer à la main. DÉCIDÉ (fiche 0074, Jeremy, 2026-10-08) : modules successifs, mêmes dimensions, taille et composants que le Lab, carton, outils du ménage. **PROPOSÉ** : les niveaux (`params/capacites.yaml`, `profils.kit.modules`) et les hypothèses (`params/kit.yaml`). Rien n'est choisi ni acheté (fiche 0066).

**Taille du Kit : GELÉE** (meilleure solution du Lab AVANT la fiche 0075 (explorateur du 2026-10-08, petits axes Dynamixel) : 0,65 → 0,715 m, 13,6 kg) : jambe à H = 0,65 m, hauteur réelle 0,715 m. **Le Lab d'aujourd'hui** (docs/explorateur-lab-2026-10.md, § 12S, 250 Hz, coupure 3,0 V, chaîne compacte, ensemble 27 (après la fiche 0075)) : 0,850 m, 18,5 kg, petits axes en feetech : la contrainte Feetech (fiche 0075) l'a fait grandir ; le Kit le suivra-t-il ? Question à Jeremy (`params/kit.yaml`, `kit_taille`). Marge 1,5 sur le couple (fiche 0051).

## Structure en carton

Carton de référence : **carton_ondule_double**, 649 g/m², 3,5 mm (mesuré (params/mesures.yaml)). Coques fermées par segment ; section des segments à servo ≥ 45,2 mm (plus grand servo Feetech) + deux parois ; × 1,5 pour les renforts.

| Segment | Nombre | Section (mm) | Longueur (mm) | Aire (dm²) | Masse unitaire (g) |
| --- | ---: | --- | ---: | ---: | ---: |
| bassin | 1 | 52 × 132 | 26 | 2,35 | 23 |
| tronc | 1 | 96 × 121 | 263 | 13,72 | 134 |
| cuisse | 2 | 52 × 52 | 161 | 3,91 | 38 |
| tibia | 2 | 52 × 52 | 147 | 3,62 | 35 |
| pied | 2 | 100 × 38 | 13 | 1,11 | 11 |
| bras | 2 | 52 × 52 | 124 | 3,14 | 31 |
| avant_bras | 2 | 52 × 52 | 98 | 2,60 | 25 |
| main | 2 | 19 × 11 | 72 | 0,47 | 5 |
| tete | 1 | 76 × 68 | 84 | 3,46 | 34 |

**Structure : 480 g.** Selon le carton (même géométrie) :

| Carton | Masse surfacique (g/m²) | Épaisseur (mm) | Structure (g) | Source |
| --- | ---: | ---: | ---: | --- |
| carton_ondule_double | 649 | 3,5 | 480 | mesuré (params/mesures.yaml) |
| kapa_line_3mm_modulor | 506 | 3,0 | 369 | marché (plume) |
| kapa_line_5mm_modulor | 582 | 5,0 | 446 | marché (plume) |
| kapa_line_10mm_modulor | 798 | 10,0 | 689 | marché (plume) |
| kapa_line_5mm_boesner | 582 | 5,0 | 446 | marché (plume) |
| ondule_b_simple_face_rouleau_udobaer | 157 | 2,1 | 112 | marché (ondule_simple) |
| claycote_b_kraft_bd | 405 | 3,0 | 295 | marché (ondule_simple) |
| claycote_c_bd | 415 | 3,3 | 305 | marché (ondule_simple) |
| claycote_e_blanc_bd | 476 | 1,5 | 334 | marché (ondule_simple) |
| claycote_eb_twin_bd | 826 | 4,5 | 625 | marché (ondule_double) |
| graukarton_1mm_modulor | 700 | 1,0 | 485 | marché (gris_compact) |
| graukarton_2mm_modulor | 1 150 | 2,0 | 817 | marché (gris_compact) |
| graukarton_3mm_modulor | 1 830 | 3,0 | 1 334 | marché (gris_compact) |
| callos_buchbinder_2mm_boesner | 1 320 | 2,0 | 938 | marché (gris_compact) |
| callos_buchbinder_3mm_boesner | 1 890 | 3,0 | 1 378 | marché (gris_compact) |
| graupappe_gpf_europapier | 1 800 | 2,2 | 1 287 | marché (gris_compact) |
| pp_alveolaire_3mm_modulor | 450 | 3,0 | 328 | marché (autre) |
| siebdruckkarton_finnboard_2mm_modulor | 1 020 | 2,0 | 725 | marché (autre) |

## Classement des cartons (critères PROPOSÉS, `params/kit.yaml`)

Aire de carton du Kit, renforts compris : 0,74 m². Éliminatoires : filière papier mono-matière ; un panneau (pas un simple face) ; disponible en Suisse. Rang : e²/σ (proxy de la rigidité en flexion par masse, que les essais remplaceront), puis masse, puis prix. **Rien n'est choisi.**

| Rang | Carton | Famille | e (mm) | σ (g/m²) | e²/σ | Structure (g) | Prix structure (CHF) | Disponibilité |
| ---: | --- | --- | ---: | ---: | ---: | ---: | ---: | --- |
| 1 | carton_ondule_double | ondule_double | 3,5 | 649 | 0,0189 | 480 | — | récupération (carton mesuré) |
| 2 | graukarton_3mm_modulor | gris_compact | 3,0 | 1 830 | 0,0049 | 1 351 | 5 | livraison en Suisse par Modulor (frais standard 36,90 € par  |
| 3 | callos_buchbinder_3mm_boesner | gris_compact | 3,0 | 1 890 | 0,0048 | 1 396 | 5 | oui, boesner.ch (« Online auf Lager ») |
| 4 | siebdruckkarton_finnboard_2mm_modulor | autre | 2,0 | 1 020 | 0,0039 | 753 | 8 | livraison en Suisse par Modulor (frais standard 36,90 € par  |
| 5 | graukarton_2mm_modulor | gris_compact | 2,0 | 1 150 | 0,0035 | 849 | 4 | livraison en Suisse par Modulor (frais standard 36,90 € par  |
| 6 | callos_buchbinder_2mm_boesner | gris_compact | 2,0 | 1 320 | 0,0030 | 975 | 4 | oui, boesner.ch (« Online auf Lager ») |
| 7 | graukarton_1mm_modulor | gris_compact | 1,0 | 700 | 0,0014 | 517 | 3 | livraison en Suisse par Modulor (frais standard 36,90 € par  |
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

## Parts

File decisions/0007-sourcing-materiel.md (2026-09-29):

# 0007 — Sourcing des affirmations sur le matériel

Date : 2026-09-28
Espèce : close
État : appliquée
Statut : acceptée

## Contexte

Le chantier 3 a établi que, sur les 30 articulations, **20 n'ont aucune
source documentaire décrivant leur mécanisme**. La documentation
matérielle amont — nomenclature, manuel d'assemblage, PCB, impression 3D,
603 lignes au total — dit quoi acheter et comment assembler, jamais
comment une liaison est constituée.

La seule source autoritative est le **document Onshape** référencé par la
doc amont (`cad.onshape.com/documents/5aba041c…`). La question se pose
donc de l'ouvrir pour lever ces 20 inconnues.

## Décision

### 1. Onshape n'est pas une source de référence du projet

**Motif : il n'est pas couvert par l'ancrage.** La fiche 0002 fige le
dépôt amont au commit `e337f3b177b4b53abff70b31d1695a7b66cc6d2e` ; le
document Onshape, lui, est un document **vivant**. Il peut être modifié,
réorganisé ou supprimé **sans laisser de trace** et sans qu'aucun SHA ne
le signale.

Y puiser massivement reviendrait à réintroduire, au cœur des paramètres
mécaniques, exactement l'irreproductibilité que les fiches 0002, 0003 et
0006 ont été écrites pour éliminer. Une cote relevée aujourd'hui sur
Onshape serait, dans six mois, indistinguable d'une valeur inventée.

Le projet en a déjà fait les frais à petite échelle : la note sur le
genou de `params/joints.yaml` était vraie pour ToddlerBot 1.0 et fausse
pour la 2.0, sans que rien ne le signale.

### 2. Consultation ponctuelle, articulation par articulation

Onshape sera ouvert **au moment de dessiner une pièce qui s'y rattache**,
pour **une articulation à la fois**, jamais en relevé massif.

Chaque consultation est **datée dans le fichier**, au même titre qu'une
empreinte :

```yaml
    materiel:
      transmission: <ce qui a été constaté>
      version: "ToddlerBot 2.0.0"
      confiance: releve_onshape
      source: "Onshape 5aba041c…, consulté le AAAA-MM-JJ"
```

La date **est** la traçabilité : elle ne prouve pas que le document n'a
pas changé, mais elle dit précisément à quel état il se rapporte. C'est
le maximum atteignable sur une source qui ne se versionne pas, et cela
doit être énoncé comme tel plutôt que masqué.

### 3. Les 20 inconnues ne bloquent rien aujourd'hui

Aucune pièce n'est en cours de conception ; `parts/`, `robot/` et `bom/`
sont vides. Ces inconnues **bloqueront une pièce à la fois**, au moment
où elles deviendront pertinentes — et c'est précisément à ce moment
qu'une consultation ciblée aura du sens.

Le champ `confiance: inconnue` est là pour que ce blocage soit
**visible** quand il surviendra, au lieu d'être découvert après avoir
dessiné un support de moteur au mauvais endroit.

## Conséquences

- Toute affirmation sur le matériel porte une `source` et une `version`.
  **Une affirmation sans version est une affirmation périmable**, comme
  l'a montré le genou.
- `confiance: releve_onshape` est une quatrième valeur du vocabulaire,
  réservée aux relevés ponctuels et toujours accompagnée d'une date.
- Ce refus ne vaut pas jugement sur Onshape comme outil de conception :
  il porte uniquement sur son usage comme **source de vérité
  reproductible**.

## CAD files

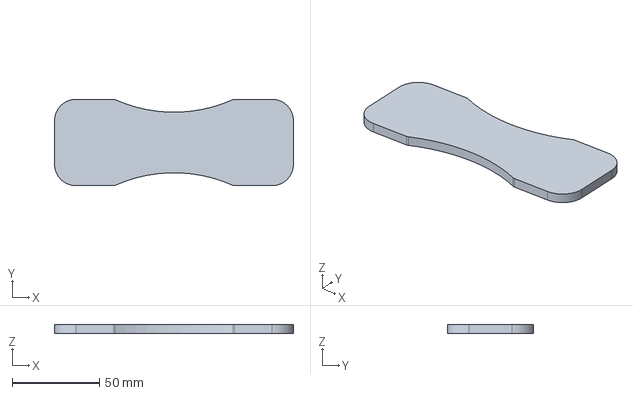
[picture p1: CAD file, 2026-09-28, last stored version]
site/fichiers/semelle_apprentissage_P2_cutter_carton.step
136.8 x 49.5 x 5.00 mm

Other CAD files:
site/fichiers/semelle_apprentissage_P2_cutter_carton.dxf
site/fichiers/semelle_apprentissage_P2_cutter_carton.stl

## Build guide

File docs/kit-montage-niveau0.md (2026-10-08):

# YXOR Kit, niveau 0 : notice de montage

**Engendrée** par `.venv/bin/python parts/kit_niveau0.py` : ne pas éditer à la main. Planches : `exports/parts/kit_niveau0_planchesA4.pdf` (hors de Git, règle 4 ; régénérées par `scripts/regenerer.py`).

Décidé (fiche 0075, Jeremy, 2026-10-08) : assemblage B — tenons et mortaises, colle non porteuse seulement, pivots par vis traversante. Carton dessiné : ondulé double de 3,5 mm (la valeur mesurée ; consigne du prompt, pas un choix écrit par Jeremy). Toutes les cotes de dessin non anthropométriques sont des hypothèses PROPOSÉES (`params/kit.yaml`, `niveau0`).

## Ce que donnent les plans

- **111 gabarits, 178 pièces à découper** (les pièces d'un bras ou d'une jambe se coupent deux fois : la seconde, gabarit retourné), plus **44 cales** (rondelles de carton de 16 mm), sur **40 feuilles A4**, dont des grandes pièces en tuiles (K52 tronc.flanc+ : 1 × 2 feuilles; K53 tronc.flanc- : 1 × 2 feuilles; K54 tronc.face+ : 1 × 2 feuilles; K55 tronc.face- : 1 × 2 feuilles).
- **Carton : 0,78 m²**, soit **505 g** à 649 g/m² (masse surfacique mesurée), sans les chutes.
- **Hauteur du Kit : 0,938 m**, contre 0,715 m pour le Lab de référence (taille du Kit GELÉE en attendant Jeremy : avec les Feetech aux petits axes, fiche 0075, le Lab passe à 0,850 m ; `params/kit.yaml`, `kit_taille`). Les longueurs entre axes sont celles du Lab de référence ; l'écart vient des logements de servo en carton (tableau ci-dessous).
- **Contrôles** : aucune faute de dessin (rayons rentrants ≥ 1,75 mm, aucun angle rentrant vif, chaque pièce d'un seul tenant) ; aucune interpénétration en 3D, servos du niveau 1 et 3 compris (un tenon sans sa mortaise, ou un servo qui ne passerait pas, se verrait).

## Hauteurs (axes au repos, debout)

| Repère | Kit (mm) | Commentaire |
| --- | ---: | --- |
| cheville | 56 | ANSUR 26 : le bas du tibia doit passer au-dessus du pied |
| genou | 203 | cheville + tibia (Lab) |
| hanche, tangage | 364 | genou + cuisse (Lab) |
| hanche, roulis | 417 | trois axes de hanche empilés (chez l'humain, ils se croisent) |
| dessous du bassin | 447 | servo de lacet de hanche |
| épaule | 763 | tronc du Lab, rallongé pour l'électronique |
| cou, tangage | 816 | |
| sommet | 938 | |

Écart de largeur : le bassin fait 179 mm (ANSUR 132), pour loger les deux servos de lacet sous les hanches, à l'écartement ANSUR.

## Ce qu'il faut savoir avant de couper

1. **Imprimer à 100 %**, sans « ajuster à la page ». Mesurer le réglet de 100 mm de chaque feuille : s'il ne fait pas exactement 100 mm, réimprimer.
2. **Reporter** : coller la feuille sur le carton (colle en bâton, ou scotch de peintre aux coins), en alignant la **flèche grise** sur le sens des **cannelures** (les petites arches visibles sur la tranche). Une pièce coupée à 90° de la flèche plie deux à trois fois plus facilement.
3. **Couper** au cutter, sur une planche ou un carton martyr, contre la règle, en deux ou trois passes légères plutôt qu'une forte. Les **mortaises** (fentes de la largeur du carton) : deux traits longs, puis les bouts. Les **petits ronds** aux coins des fentes et des fenêtres (les « os de chien ») laissent entrer un tenon carré jusqu'au fond : un coup de pointe de cutter suffit.
4. **Trous de pivot** (Ø 4,5 mm) : percer au poinçon ou à la pointe d'un tournevis, puis agrandir en vissant la vis M4 à travers.
5. **Grandes pièces** (tronc) : imprimées en plusieurs feuilles qui se recouvrent de 10 mm ; poser les croix grises les unes sur les autres, scotcher, puis reporter comme une seule feuille.
6. **Côté droit** : les pièces des bras et des jambes se coupent deux fois ; pour la seconde, retourner le gabarit (le carton n'a pas d'endroit).

## Montage d'un caisson (toutes les boîtes se montent pareil)

1. Poser un **flanc** à plat.
2. Enfoncer les **tenons** des deux **faces** dans les mortaises du flanc, faces debout.
3. Glisser les **cloisons** et les **plaques à fenêtre** (s'il y en a) : leurs tenons entrent dans les faces et les flancs.
4. Poser le second flanc par-dessus : tous les tenons dans ses mortaises.
5. Poser les **couvercles** sur les bouts : les tenons des flancs et des faces les traversent.
6. **Colle (non porteuse)** : un point de colle chaude sur un tenon qui dépasse, pour qu'il ne ressorte pas. Jamais entre deux pièces qui portent un effort, jamais sur un bouchon ni une plaque de serrage (ils s'enlèvent au niveau 1).

## Logements de servo : ce qui se pose au niveau 0

Chaque logement est une **fenêtre** dans une paroi, à la taille du servo STS3215 (45,23 × 24,73 mm, plus 1,0 mm de jeu), et une **plaque à fenêtre** intérieure qui tiendra le servo à mi-hauteur. Au niveau 0 :
- le **bouchon** (pièce à la taille de la fenêtre, percée sur l'axe) ferme la fenêtre ;
- la **plaque de serrage** (un peu plus grande) se pose derrière, à l'intérieur ;
- la vis du pivot traverse : oreille ou couvercle de l'enfant, deux **cales** (rondelles de carton), bouchon, plaque de serrage ; écrou à frein derrière.
Au niveau 1 (ou 3), on retire la vis, le bouchon et la plaque de serrage, on glisse le servo par la fenêtre, sa sortie à l'emplacement du trou : **rien n'est redécoupé**. Les trous du palonnier se percent alors dans l'oreille, d'après le palonnier livré (non coté par Feetech).

## Pivots

| Articulation | Sorte | Parent → enfant | Nombre | Vis côté servo | Vis côté opposé | Cales côté opposé |
| --- | --- | --- | ---: | --- | --- | --- |
| hip_yaw | plateau (servo au niveau 3) | bassin → hanche1 | 2 | M4×25 | — | 0 cale(s) de carton + 0,0 mm en rondelles |
| hip_roll | chape (servo au niveau 3) | hanche1 → hanche2 | 2 | M4×25 | M4×25 | 1 cale(s) de carton + 2,6 mm en rondelles |
| hip_pitch | chape (servo au niveau 3) | hanche2 → cuisse | 2 | M4×25 | M4×16 | 0 cale(s) de carton + 1,0 mm en rondelles |
| knee | chape (servo au niveau 3) | tibia → cuisse | 2 | M4×25 | M4×20 | 1 cale(s) de carton + 1,0 mm en rondelles |
| ankle_pitch | chape (servo au niveau 3) | tibia → pied | 2 | M4×25 | M4×16 | 0 cale(s) de carton + 1,0 mm en rondelles |
| waist_yaw | plateau (servo au niveau 3) | bassin → tronc | 1 | M4×25 | — | 0 cale(s) de carton + 0,0 mm en rondelles |
| shoulder_pitch | plateau (servo au niveau 1) | tronc → epaule | 2 | M4×25 | — | 0 cale(s) de carton + 0,0 mm en rondelles |
| shoulder_roll | chape (servo au niveau 1) | epaule → bras | 2 | M4×25 | M4×16 | 0 cale(s) de carton + 1,0 mm en rondelles |
| elbow_roll | chape (servo au niveau 1) | bras → avant_bras | 2 | M4×25 | M4×16 | 0 cale(s) de carton + 1,0 mm en rondelles |
| neck_yaw | plateau (servo au niveau 1) | tronc → cou | 1 | M4×25 | — | 0 cale(s) de carton + 0,0 mm en rondelles |
| neck_pitch | chape (servo au niveau 1) | cou → tete | 1 | M4×25 | M4×25 | 2 cale(s) de carton + 3,0 mm en rondelles |
| wrist_roll | plateau passif | avant_bras → poignet | 2 | M4×16 | — | 0 cale(s) de carton + 0,0 mm en rondelles |
| wrist_pitch | chape passive | poignet → main | 2 | M4×16 | M4×16 | 0 cale(s) de carton + 1,0 mm en rondelles |

## Ce qu'il faut réunir pour le niveau 0

- carton ondulé **double cannelure** de 3,5 mm (cartons de déménagement de récupération) : **1,2 m²** au moins (0,78 m² de pièces × 1,5 pour les chutes, PROPOSÉ), plats, secs, sans pli marqué ;
- **38 vis M4** à tête, 14 × 16 mm, 2 × 20 mm, 22 × 25 mm ; **38 écrous M4 à frein** (nylstop) ; **76 rondelles larges M4** ;
- **40 feuilles A4** imprimées à 100 %, colle en bâton ou scotch de peintre pour les poser sur le carton ;
- outils (décidés, fiche 0074) : **cutter** (lames neuves), **règle métallique**, **équerre**, **pistolet à colle** (colle non porteuse seulement) ; un **carton martyr** ou une planche sous la coupe ; un **tournevis cruciforme** ou un poinçon pour amorcer les trous Ø 4,5 ; un tournevis ou une clé pour les vis M4.

« Plateau » : l'enfant est vissé par un couvercle sur la sortie du servo (un seul pivot) ; « chape » : les oreilles de l'enfant encadrent le parent, un pivot de chaque côté, sur le même axe. Le débattement libre garanti par le dessin est de ±15° autour de la pose debout (PROPOSÉ) ; au-delà, à essayer.

## Ordre de montage du robot

1. **Jambes** (×2) : pied, tibia (avec ses deux bouchons), cuisse ; pivots de cheville et de genou.
2. **Hanches** (×2) : noix 2 sur la cuisse (tangage), noix 1 dans les oreilles de la noix 2 (roulis).
3. **Bassin** : visser chaque noix 1 sous le couvercle bas (lacets de hanche).
4. **Tronc** sur le couvercle haut du bassin (lacet de taille).
5. **Épaules** (×2) sur les flancs du tronc, puis **bras**, **avant-bras**, **poignet**, **main**.
6. **Cou** sur le couvercle haut du tronc, puis **tête**.

## Pièces par caisson

| Caisson | Pièces (identifiant, nom, nombre à couper, dimensions en mm) |
| --- | --- |
| pied | K01 flanc+ ×2 (81 × 100) ; K02 flanc- ×2 (81 × 100) ; K03 face+ ×2 (30 × 59) ; K04 face- ×2 (30 × 59) ; K05 cloison1 ×2 (59 × 93) ; K06 couvercle_bas ×2 (73 × 114) |
| tibia | K07 flanc+ ×2 (183 × 54) ; K08 flanc- ×2 (183 × 54) ; K09 face+ ×2 (183 × 44) ; K10 face- ×2 (183 × 44) ; K11 knee.plaque ×2 (72 × 47) ; K12 ankle_pitch.plaque ×2 (72 × 47) ; K13 knee.bouchon ×2 (46 × 26) ; K14 knee.serrage ×2 (58 × 38) ; K15 ankle_pitch.bouchon ×2 (46 × 26) ; K16 ankle_pitch.serrage ×2 (58 × 38) |
| cuisse | K17 flanc+ ×2 (215 × 54) ; K18 flanc- ×2 (215 × 54) ; K19 face+ ×2 (102 × 62) ; K20 face- ×2 (102 × 62) ; K21 cloison1 ×2 (62 × 47) ; K22 cloison2 ×2 (62 × 47) |
| hanche2 | K23 flanc+ ×2 (92 × 51) ; K24 flanc- ×2 (92 × 51) ; K25 face+ ×2 (40 × 67) ; K26 face- ×2 (40 × 67) ; K27 hip_pitch.plaque ×2 (40 × 67) ; K28 hip_pitch.bouchon ×2 (26 × 46) ; K29 hip_pitch.serrage ×2 (38 × 58) |
| hanche1 | K30 flanc+ ×2 (43 × 51) ; K31 flanc- ×2 (43 × 51) ; K32 face+ ×2 (43 × 67) ; K33 face- ×2 (43 × 67) ; K34 hip_roll.plaque ×2 (40 × 67) ; K35 couvercle_bas ×2 (81 × 65) ; K36 hip_roll.bouchon ×2 (26 × 46) ; K37 hip_roll.serrage ×2 (38 × 58) |
| bassin | K38 flanc+ ×1 (61 × 74) ; K39 flanc- ×1 (61 × 74) ; K40 face+ ×1 (61 × 179) ; K41 face- ×1 (61 × 179) ; K42 plaque_logement_bas ×1 (179 × 67) ; K43 plaque_logement_haut ×1 (179 × 67) ; K44 couvercle_bas ×1 (193 × 88) ; K45 couvercle_haut ×1 (193 × 88) ; K46 hip_yaw.bouchon ×1 (26 × 46) ; K47 hip_yaw.serrage ×1 (38 × 58) ; K48 hip_yaw_droit.bouchon ×1 (26 × 46) ; K49 hip_yaw_droit.serrage ×1 (38 × 58) ; K50 waist_yaw.bouchon ×1 (26 × 46) ; K51 waist_yaw.serrage ×1 (38 × 58) |
| tronc | K52 flanc+ ×1 (270 × 96) ; K53 flanc- ×1 (270 × 96) ; K54 face+ ×1 (270 × 151) ; K55 face- ×1 (270 × 151) ; K56 cloison1 ×1 (151 × 89) ; K57 plaque_logement_haut ×1 (69 × 89) ; K58 shoulder_pitch.plaque ×1 (52 × 89) ; K59 shoulder_pitch_droit.plaque ×1 (52 × 89) ; K60 couvercle_bas ×1 (165 × 110) ; K61 couvercle_haut ×1 (165 × 110) ; K62 shoulder_pitch.bouchon ×1 (26 × 46) ; K63 shoulder_pitch.serrage ×1 (38 × 58) ; K64 shoulder_pitch_droit.bouchon ×1 (26 × 46) ; K65 shoulder_pitch_droit.serrage ×1 (38 × 58) ; K66 neck_yaw.bouchon ×1 (26 × 46) ; K67 neck_yaw.serrage ×1 (38 × 58) |
| cou | K68 flanc+ ×1 (43 × 74) ; K69 flanc- ×1 (43 × 74) ; K70 face+ ×1 (43 × 44) ; K71 face- ×1 (43 × 44) ; K72 neck_pitch.plaque ×1 (40 × 67) ; K73 couvercle_bas ×1 (58 × 88) ; K74 neck_pitch.bouchon ×1 (26 × 46) ; K75 neck_pitch.serrage ×1 (38 × 58) |
| tete | K76 flanc+ ×1 (151 × 76) ; K77 flanc- ×1 (151 × 76) ; K78 face+ ×1 (88 × 68) ; K79 face- ×1 (88 × 68) ; K80 cloison1 ×1 (68 × 69) ; K81 couvercle_haut ×1 (82 × 90) |
| epaule | K82 flanc+ ×2 (64 × 51) ; K83 flanc- ×2 (64 × 51) ; K84 face+ ×2 (64 × 47) ; K85 face- ×2 (64 × 47) ; K86 shoulder_roll.plaque ×2 (60 × 47) ; K87 couvercle_bas ×2 (61 × 65) ; K88 shoulder_roll.bouchon ×2 (46 × 26) ; K89 shoulder_roll.serrage ×2 (58 × 38) |
| bras | K90 flanc+ ×2 (167 × 51) ; K91 flanc- ×2 (167 × 51) ; K92 face+ ×2 (105 × 62) ; K93 face- ×2 (105 × 62) ; K94 elbow_roll.plaque ×2 (72 × 62) ; K95 elbow_roll.bouchon ×2 (46 × 26) ; K96 elbow_roll.serrage ×2 (58 × 38) |
| avant_bras | K97 flanc+ ×2 (99 × 51) ; K98 flanc- ×2 (99 × 51) ; K99 face+ ×2 (47 × 62) ; K100 face- ×2 (47 × 62) ; K101 couvercle_haut ×2 (76 × 65) |
| poignet | K102 flanc+ ×2 (44 × 40) ; K103 flanc- ×2 (44 × 40) ; K104 face+ ×2 (44 × 40) ; K105 face- ×2 (44 × 40) ; K106 couvercle_bas ×2 (54 × 54) |
| main | K107 flanc+ ×2 (94 × 49) ; K108 flanc- ×2 (94 × 49) ; K109 face+ ×2 (49 × 49) ; K110 face- ×2 (49 × 49) ; K111 couvercle_haut ×2 (63 × 63) |

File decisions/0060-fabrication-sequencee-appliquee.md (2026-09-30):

# 0060 — Les plaques et entretoises ne sont plus le procédé unique

Date : 2026-09-30
Espèce : gouvernante
État : acceptée
Statut : **acceptée** — lot de cohérence validé par Jeremy le 2026-09-30 (~23 h), point 4. Appliquée dans CLAUDE.md (point 5 du même lot) ; aucune pièce nouvelle.
Remplace : `0015-architecture-plaques-entretoises.md`

## Pourquoi remplacer la 0015

La 0015 disait : « YXOR est conçu en plaques et entretoises, **découpe 2D
exclusivement** ». Elle faisait du carton le cas de conception le plus
contraignant. La 0050 décide une **fabrication séquencée** : usinage,
puis impression 3D, puis hybride. Le carton n'y est plus qu'une
**maquette rapide, sans métrologie** (cadrage § 1, principe 4 ;
caractérisation du carton arrêtée le 2026-09-30).

## La décision

1. **La découpe 2D n'est plus le procédé unique.** Plaques et entretoises
   restent **une** architecture possible, parmi l'usinage, l'impression
   et l'hybride. Le procédé se choisit pièce par pièce, dans l'ordre de
   la 0050.
2. **« Concevoir au plus contraignant, au carton » est retiré.** Le
   carton sert à vérifier une forme, une taille, un emboîtement. Il ne
   borne plus la conception, et aucune cote n'est tirée de ses mesures.
3. **Ce qui reste vrai pour toute pièce découpée en 2D**, quel que soit
   le matériau :
   - contour fermé, en millimètres, à l'échelle 1:1 ;
   - rayon intérieur au moins égal à 0,5 × l'épaisseur ;
   - saignée **mesurée** par couple machine-matériau ;
   - épaisseur et saignée en **paramètres**.
4. **Ce qui reste vrai pour toute pièce** :
   - assemblage démontable, sans collage structurel ;
   - pas de logement de roulement obtenu directement par le procédé ;
   - vis traversante et écrou, sauf un insert posé dans une pièce
     imprimée (0059).
5. **Restent ouverts** :
   - le procédé exact de l'opérateur CN : rayons d'outil, matières,
     format de fichier (cadrage, question 6) ;
   - les douze transmissions à engrenage ou à différentiel que la 0015
     rouvrait (§ Décision, point 4). Leur déclencheur devient **la
     conception des jambes de S**.

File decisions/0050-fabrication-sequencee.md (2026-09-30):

# 0050 — Fabrication séquencée : usinage, puis impression 3D, puis hybride

Date : 2026-09-30
Espèce : gouvernante
État : acceptée
Statut : **acceptée** — décidée par Jeremy le 2026-09-30. **Rien n'est appliqué**, et les fiches 0014 et 0015 ne sont PAS remplacées ici (question ouverte 9 du cadrage).

## La décision

Les pièces du robot sont fabriquées **dans cet ordre** : d'abord par
usinage, puis par impression 3D, puis en hybride. Le carton reste une
maquette rapide, sans métrologie.

## Où est le raisonnement

`docs/cadrage.md`, § 1 (principe 4) et registre (§ 12) : comprendre
chaque procédé, ses avantages et ses limites. Les alternatives écartées
sont « tout imprimé » et « plaques seules ». Le § 7.2 ajoute que le
procédé change peu le budget.

## Ce qu'elle laisse en l'état, et pourquoi c'est une contradiction assumée

Cette décision **contredit** deux textes toujours en vigueur :

- la fiche **0014** (« il n'y a pas d'imprimante 3D ») ;
- la fiche **0015** (plaques et entretoises, découpe 2D seule), et avec
  elle la section « Contraintes de fabrication » de **CLAUDE.md**
  (« procédé unique : la découpe 2D »).

Ils **ne sont pas modifiés**. Leur réouverture passera par des fiches
qui les remplacent sans les réécrire : c'est la **question ouverte 9**
du cadrage. D'ici là, les deux textes coexistent, et c'est celui-ci qui
dit la direction.

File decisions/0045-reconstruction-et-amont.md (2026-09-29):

# 0045 — Aucune géométrie amont ne passe dans un outil de reconstruction

Date : 2026-09-30
Espèce : gouvernante
État : acceptée
Statut : **acceptée** — règle posée par Jeremy, écrite **avant** tout test d'outil de reconstruction (fiche 0046). Non outillée, et dite comme telle.
Découle de : `0010-origine-des-cotes.md`, `0029-familles-de-licences.md`

## La règle

> **Aucune géométrie d'origine `amont` ne passe dans un outil de
> reconstruction pour en tirer une pièce, une esquisse ou une cote YXOR.**
>
> Un **outil de reconstruction** est tout procédé automatisé qui
> produit une géométrie à partir d'une autre représentation. Cela
> couvre :
>
> - le scan vers la CAO ;
> - le maillage vers la CAO (STL, OBJ, PLY) ;
> - le plan vers la CAO, qu'il s'agisse d'un dessin technique ou d'une
>   image ;
> - la photo vers la CAO ou vers un maillage ;
> - tout générateur 3D par IA.
>
> La règle vaut pour **tous** ces outils, et pas pour un produit en
> particulier.
>
> Une **géométrie amont** est tout ce qui représente la mécanique de
> ToddlerBot, sous n'importe quelle forme :
>
> - les maillages du dépôt amont ;
> - le document Onshape et ses exports ;
> - les rendus, captures et vidéos, y compris ceux produits par
>   `sim/upstream/` ;
> - les photos d'un ToddlerBot physique ;
> - les plans et les mesures prises sur l'un de ces supports.

## Pourquoi

**Une reconstruction ne transforme pas une œuvre dérivée en conception
originale. Elle produit une dérivation mieux documentée.**

La fiche 0010 existe pour pouvoir dire, cote par cote, ce qui vient de
l'amont. Un outil de reconstruction ferait l'inverse. Il prendrait une
géométrie `amont` et rendrait un arbre de features propre, avec des
esquisses et des cotes nommées, qui a **l'apparence** d'un travail
original. La provenance serait perdue au moment précis où elle
compterait le plus. Dans le pire des cas, l'audit la classerait
`propre`.

La mécanique amont est sous **CC BY-NC-SA**. C'est ce qu'écrit
`~/upstream/toddlerbot/README.md:167`, vérifié le 2026-09-29. Les deux
clauses pèsent :

- **NC** interdit l'exploitation commerciale du dérivé ;
- **SA** impose la même licence au dérivé.

Une reconstruction ne se soustrait à aucune des deux. Ce n'est pas un
avis juridique (fiche 0010 §4) : c'est le constat que l'outil ne change
pas la nature de ce qu'on lui donne.

Il y a une seconde raison, indépendante de la première. **Téléverser**
une géométrie amont dans un service tiers, c'est déjà la transmettre.
Les conditions de Backflip du 2026-08-04 accordent par défaut au
service une licence d'entraînement sur les contenus, et le droit de
partager les résultats avec d'autres utilisateurs (fiche 0046 §1).
Elles exigent aussi que l'utilisateur ait « des droits suffisants » sur
ce qu'il envoie. Même sans pièce produite, l'envoi seul poserait
problème.

## Si cela arrive quand même

Une géométrie obtenue par reconstruction d'une source `amont` est
qualifiée **`amont`**, sans exception. Elle ne peut **jamais** être
qualifiée `propre`, `mesure` ni d'une éventuelle origine « reconstruction ».

C'est la seule partie de la question 4b de la fiche 0046 que cette
fiche tranche. Elle ne fait qu'appliquer la 0010 : l'origine suit la
source, pas l'outil.

## Ce que la règle n'interdit pas

- **Reconstruire une géométrie YXOR**, dont la vérité est connue. C'est
  le test de la semelle (fiche 0046).
- **Lire une valeur amont**, avec son origine, comme le fait déjà
  `import_upstream_limits.py`. C'est un extrait tracé, et non une
  reconstruction.
- **Reconstruire depuis un objet physique ou un plan que Jeremy a le
  droit d'utiliser.** Ce cas est instruit, sans être tranché, dans la
  fiche 0046 (question 4a).

## Vérifiabilité — non outillée

**Aucun contrôle du dépôt ne peut voir ce qui est envoyé à un service
extérieur.** La règle repose sur la conduite, comme la branche (c) de la
0027. Elle est déclarée non outillée plutôt que d'être entourée d'un
garde-fou qui n'en serait pas un.

Il existe une protection partielle, **possible mais non faite** :

1. Toute reconstruction inscrit dans son registre l'empreinte du
   fichier **envoyé**.
2. Un contrôle compare cette empreinte à celles des maillages de
   `~/upstream/toddlerbot/` au commit épinglé.

Ce contrôle attraperait un envoi direct d'un STL amont. Il ne verrait
ni une photo, ni un rendu, ni un fichier converti. **Il ne prouverait
donc pas que la règle est respectée**, et c'est écrit ici pour qu'on ne
le croie pas plus fort qu'il n'est.

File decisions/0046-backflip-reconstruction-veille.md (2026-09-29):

# 0046 — Backflip AI : une CAO paramétrique reconstruite ? Vérifié, pas adopté

Date : 2026-09-30
Espèce : veille
État : veille
Statut : **veille** — aucune adoption, aucun abonnement, aucune place dans la chaîne. build123d reste la source de vérité. Un test sur la semelle est préparé ; Jeremy le lancera.
Découle de : `0045-reconstruction-et-amont.md` (écrite avant celle-ci)

## Le signalement

Un retour extérieur signale **Backflip AI**. L'outil reconstruirait une
CAO **paramétrique** — arbre de features, esquisses, STEP — depuis un
scan, un STL, un plan 2D ou des photos.

Si c'est exact, une généralisation antérieure tombe : « les générateurs
3D par IA produisent des maillages, pas des solides ». Elle reposait sur
trois outils seulement, Meshy, Rodin et Tripo.

**Cette phrase n'est pas dans le dépôt.** `grep -ri
"maillage\|Meshy\|Tripo\|Rodin"` ne la trouve dans aucune fiche, aucun
journal, aucun paramètre. La cartographie à corriger vit ailleurs. Rien
ici ne peut donc la corriger ; on peut seulement constater qu'elle
n'était pas tracée.

## 1 — Vérification, le 2026-09-30

Méthode : recherche web et lecture des pages avec un client automatique.
**Ce client passe par un modèle qui résume** : les « citations »
ci-dessous sont celles qu'il a rendues, pas un relevé caractère par
caractère.

| Affirmation | Verdict | Fondement |
| --- | --- | --- |
| **reconstruction paramétrique réelle, pas un maillage habillé** | **affirmée, non vérifiée** | Seules sources : l'éditeur et la presse spécialisée qui relaie son annonce. develop3d (4 août 2026) décrit des « modèles CAO paramétriques entièrement modifiables » avec arbre de features ; le résumé de l'article ne signale **aucun essai indépendant**. Un essai pratique existe (Fabbaloo, « Hands on with Backflip.ai ») mais il n'a pas pu être lu (HTTP 403). L'éditeur dit lui-même que l'outil excelle sur les « pièces de complexité modérée, fraisées 3 axes et tournées ». |
| **drawing-to-CAD, septembre 2026** | **vérifié, comme annonce** | develop3d, 17 septembre 2026 : lancement à Autodesk University 2026, disponible dans Fusion et dans l'application web, 5 à 30 min et « 10 $ ou moins » par pièce. **Photo-to-CAD** est annoncé en même temps. |
| **aucune API ni CLI publique** | **non trouvée — ce qui ne prouve pas l'absence** | Aucune mention d'API, de SDK ou de CLI sur la page d'accueil, dans les conditions, ni dans les deux articles. Intégrations annoncées : complément Fusion et application web ; Onshape et d'autres « à venir ». Des sources plus anciennes citent un complément SolidWorks. |
| **conditions d'août 2026 : licence d'entraînement par défaut** | **vérifié** | Conditions d'utilisation, mises à jour le **4 août 2026** : licence pour « entraîner, développer, améliorer » le service, et pour partager ou sous-licencier les modèles avec d'autres utilisateurs. **Privacy Mode** lève l'entraînement ; **Private Library Mode** lève le partage. L'utilisateur doit avoir « des droits suffisants » sur ce qu'il envoie. La propriété exclusive des résultats n'est **pas garantie**. |
| **modes Privacy à certains niveaux seulement** | **vérifié en principe, non vérifié en détail** | Les conditions renvoient la disponibilité à l'offre souscrite. La page des tarifs, lue ce jour, **ne dit pas quelles offres les incluent**. |
| **tarifs : 60 crédits d'essai, puis 20 $/mois** | **partiellement faux** | La page des tarifs, lue ce jour, dit **50 crédits** d'essai, sans carte bancaire. Builder : 20 $/mois pour 100 crédits. Pro : 50 $ pour 300. Business : 380 $ pour 2 500. Une tâche Fast coûte **10 crédits**, une tâche Thinking **50**. **L'essai permet donc cinq tâches Fast, ou une seule Thinking.** |

**Conclusion du § 1.** Quatre points sur cinq tiennent, dont un avec un
chiffre corrigé. **Le premier — le seul qui compte — n'est ni confirmé
ni infirmé** : il n'est attesté que par l'éditeur. Or c'est
précisément ce qu'un test sur une pièce dont on connaît la vérité peut
établir. Le § 2 n'est donc pas conditionné à une certitude qu'on
n'obtiendra pas autrement : **il sert à vérifier le point 1**.

### Sources

- develop3d, « Backflip AI updated engine flips mesh into feature tree-CAD model », 2026-08-04 — https://develop3d.com/ai/backflip-ai-reverse-engineering
- develop3d, « Backflip now converts 2D engineering drawings directly into CAD », 2026-09-17 — https://develop3d.com/cad/backflip-converse-2d-engineering-drawings-directly-into-cad
- Backflip, conditions d'utilisation, mises à jour le 2026-08-04 — https://www.backflip.ai/legal/terms-of-service
- Backflip, tarifs, lus le 2026-09-30 — https://www.backflip.ai/pricing
- Backflip, page d'accueil, lue le 2026-09-30 — https://www.backflip.ai/
- Fabbaloo, « Hands on with Backflip.ai » — **non lu** (403)

## 2 — Le protocole de test sur la semelle

**Rien n'est téléversé par l'assistant.** Jeremy lance le test.

### Pourquoi la semelle

- **Originale** : aucune cote `amont` (relevé de la pièce). La fiche 0045
  ne l'interdit donc pas.
- **Simple**, mais pas triviale : elle combine des congés convexes, des
  raccords concaves et un grand arc de creux. Elle permet de juger si
  l'outil reconnaît des arcs ou s'il les approche.
- **Vérité connue par construction**, et mesurée le 2026-09-29 sur le
  STEP produit à l'empreinte `7d61326025` :

| Grandeur | Vérité | Mesurée par |
| --- | ---: | --- |
| boîte englobante | **138,06 × 51,93 × 5,00 mm** | build123d, import du STEP |
| volume | **31 502,4 mm³** | idem |
| aire de la face | **6 300,46 mm²** | relevé de la pièce |
| aire totale | 14 412,28 mm² | build123d |
| faces | **18 : 8 planes, 10 cylindriques** | idem |
| arêtes | 48 : 28 droites, 20 circulaires | idem |
| congés convexes | **4 × R 12,98** | arêtes circulaires du STEP |
| raccords concaves | **4 × R 2,50** (le rayon minimal du procédé) | idem |
| arcs du creux | **2 × R 80,36**, centres en X = 0 | idem |
| largeur au creux | **36,35 mm** | relevé |
| position du creux | **au milieu de la longueur**, pièce symétrique en X et en Y | centres des arcs |

### Les entrées — trois sur quatre possibles sans scanner

| Entrée | Fichier | Outil | Disponible ? |
| --- | --- | --- | --- |
| **E1** maillage | le STL exporté (820 triangles) | Scan/Mesh to CAD | **oui**, engendré |
| **E2** plan | le PDF A4 de découpe | Drawing to CAD | **oui**, engendré — mais il n'a qu'une vue et donne l'épaisseur en texte : c'est un test difficile |
| **E3** photos | la semelle réellement coupée, en ondulé | Photo to CAD | **oui** — sa vérité est moins sûre : la pièce porte l'erreur de coupe et fait 3,5 mm, pas 5 |
| **E4** scan | — | Scan to CAD | **non : aucun scanner 3D** |

**Une nuance au constat de Jeremy.** Je ne compte pas trois usages sur
quatre qui supposent un scanner, mais **deux** : le scan lui-même, et le
STL **d'un objet physique** (un STL d'une pièce qu'on a déjà en CAO ne
sert qu'au test). D'après l'éditeur, Photo to CAD n'exige qu'un
téléphone, et Drawing to CAD un plan. Pour les usages **réels**, hors
test, l'absence de scanner ferme donc le scan et le STL d'objet
physique. La photo et le plan restent ouverts.

### Budget

L'essai donne 50 crédits, soit **cinq tâches Fast**. Plan proposé :
E1, E1 **une seconde fois** (reproductibilité : même entrée, même
sortie ?), E2, E3. Cela fait 40 crédits et en laisse 10 pour un
imprévu. **Pas de mode Thinking** : il consommerait l'essai entier sur
une seule entrée.

### Avant l'envoi

1. Régénérer, puis noter l'empreinte du site et le **sha256 de chaque
   fichier envoyé**. Le STEP est réécrit à chaque régénération : son
   empreinte n'est valable que pour l'exemplaire envoyé.
2. **Mesurer l'erreur propre de l'entrée E1** : l'écart de Hausdorff
   entre les sommets du STL et le contour exact (`profil.contour`). Un
   STL à 820 triangles approche les arcs par des cordes. Une
   reconstruction qui « rate » d'autant ne rate rien : elle recopie son
   entrée. **Sans cette ligne de base, le résultat n'est pas
   interprétable.**
3. Noter l'offre, et si Privacy Mode est **disponible et activé**. À
   l'essai, il ne l'est probablement pas : **la semelle servirait alors
   à l'entraînement.** Pour cette pièce, c'est acceptable (elle est
   publiée sur `yxor.fr`). Cela doit néanmoins être écrit.

### Ce qu'on compare

**Portes binaires d'abord.** Chacune dit si le résultat est une CAO ou
un maillage déguisé :

| Porte | Attendu |
| --- | --- |
| solide fermé, valide | oui |
| types de surfaces | **plans et cylindres seulement**. Une B-spline ou des centaines de facettes planes = un maillage habillé. |
| nombre de faces | 18, ou proche avec une justification |
| arbre de features | au moins une esquisse et une extrusion |
| **paramétrique pour de vrai** | dans Fusion, passer l'extrusion de 5 à 3,5 mm et réexporter : **volume attendu 22 051,7 mm³**, à 0,1 % près |

La dernière porte est **la seule qui réponde au point 1**. Un arbre qui
ne se laisse pas modifier n'est pas paramétrique, quel que soit son
aspect.

**Puis les grandeurs**, en écart à la vérité : boîte englobante,
volume, aire de face, les trois familles de rayons, la largeur au creux,
la position des centres, et **l'écart de Hausdorff du contour**. Pour ce
dernier, on coupe le STEP rendu à mi-épaisseur et on le compare à
`profil.contour` avec `profil.hausdorff`, qui existent déjà.

### Seuils

| Niveau | Seuil | Justification |
| --- | --- | --- |
| **fidèle** | Hausdorff ≤ **0,05 mm**, volume à 0,1 % près, rayons à 0,05 mm près | C'est `TOLERANCE_MM` de `profil.py` : la tolérance déjà admise entre deux implémentations de la **même** forme. |
| **exploitable pour la découpe** | Hausdorff ≤ **0,5 mm**, rayons à 0,25 mm près | **Déduit, pas mesuré.** C'est l'ordre de grandeur d'une coupe au cutter guidé à la main et d'une lecture à la règle à demi-graduation (`mesures.yaml`). Aucune mesure du dépôt n'établit encore la précision du geste (fiche 0042). |
| **inexploitable** | une porte binaire qui échoue, **ou** un écart supérieur à 0,5 mm | — |

Pour **E3**, seul le second seuil s'applique, et l'épaisseur attendue est
3,5 mm. La pièce coupée n'est pas la vérité : elle en est un exemplaire.

### Où vivrait l'expérience — proposé, rien de créé

- **Les fichiers rendus par Backflip** (STEP, exports Fusion) : **hors
  Git**. Ils ne se régénèrent pas, ils sont tiers, et leur propriété
  n'est pas garantie par les conditions. Ils seraient rangés hors du
  dépôt et inscrits au registre de la fiche 0030
  (`params/fournisseurs.yaml`), avec les six champs. Il faudrait y
  ajouter : sha256 de l'**entrée**, mode, offre, Privacy Mode oui ou
  non, version des conditions (2026-08-04).
- **Le protocole et les résultats chiffrés** : un répertoire
  `experiences/2026-09-backflip-semelle/`, en texte, **hors de
  `params/`**. S'ils étaient dans `params/`, `audit_origines` exigerait
  une origine pour chaque écart mesuré, et ces nombres ne sont pas des
  cotes.
- **La comparaison** : un script `scripts/comparer_reconstruction.py`,
  qui applique les portes et les seuils ci-dessus au STEP rendu. Il est
  **à écrire après décision**, pas avant.

## 3 — La règle, écrite avant le test

Elle est dans la **fiche 0045**, qui la pose pour tout outil de
reconstruction. Elle a été écrite avant celle-ci et avant tout envoi.

## 4 — Deux questions que le retour ne pose pas

**Instruites, pas tranchées.**

### a) Reconstruire depuis un plan constructeur sous droits

La fiche 0030 définit un fichier fournisseur comme « tout fichier
obtenu d'un catalogue, constructeur ou distributeur : modèle CAO,
**plan**, nomenclature… ». **Un plan constructeur en est un.**

**Le cas est-il analogue à McMaster ?** Sur le point essentiel, oui :
la clause citée par la 0030 vise nommément **la création d'œuvres
dérivées**. Une CAO reconstruite depuis un plan est une œuvre dérivée
de ce plan, au même titre qu'un modèle McMaster retouché. **La
reconstruction ne blanchit pas plus un plan fournisseur qu'une
géométrie amont** : c'est le même raisonnement que la 0045.

**Deux différences, qui compliquent :**

1. **L'envoi lui-même.** Chez McMaster, le fichier reste sur le poste.
   Ici, il part chez un tiers qui, par défaut, s'accorde une licence
   d'entraînement et de partage. On pourrait enfreindre les conditions
   du plan **avant même d'avoir une pièce**.
2. **Le fait et l'œuvre.** CLAUDE.md distingue déjà les deux : « une
   valeur, jamais le texte ». L'entraxe de fixation d'un servomoteur,
   relevé sur son plan et cité avec sa référence, est **un fait**,
   c'est-à-dire une cote d'interface (règle 2). La géométrie complète
   du boîtier, reconstruite, relève de **l'œuvre**. Le dépôt sait déjà
   prendre la première sans la seconde, **sans aucun outil de
   reconstruction**.

**Question restée ouverte** : un plan constructeur **publié pour être
utilisé**, comme le plan d'encombrement d'un servomoteur, change-t-il
quelque chose ? Cela dépend des conditions de **chaque** plan. Il n'y a
pas de réponse générale, et ce n'est pas un avis juridique (0010 §4).

### b) Quelle origine pour une cote issue d'une reconstruction ?

Ni `catalogue`, ni `mesure`, ni `propre`, en effet. Trois voies :

| Voie | Principe | Ce qu'elle coûte |
| --- | --- | --- |
| **A. Nouvelle origine `reconstruction`** | symétrique de `norme` (0035) | **Elle efface la source.** Une cote reconstruite depuis l'amont sortirait de la colonne `amont` de l'audit. C'est le blanchiment que la 0045 interdit, **rendu possible par la taxonomie elle-même**. |
| **B. Origine héritée de l'entrée, plus un champ de transformation** | l'origine est celle de ce qu'on a envoyé (`propre` pour la semelle, `mesure` pour un scan, `catalogue` pour un plan constructeur, `amont` pour ToddlerBot) ; un champ `obtenue_par: reconstruction` porte l'outil, la date et l'empreinte de l'entrée | Un axe de plus. Mais c'est la forme de la 0035 corrigée : un axe **calculé** à partir d'un fait, pas une origine déclarée. |
| **C. Une reconstruction n'est jamais une source** | elle sert à **contrôler** (comparer à une mesure), jamais à **fournir** une cote | La plus simple. Elle ferme l'usage « rétro-ingénierie d'une pièce du commerce », qui est pourtant le cas d'usage annoncé de l'outil. |

**Une asymétrie à noter, sans conclure** : A est la seule voie
incompatible avec la 0045. B demande que l'incertitude de la
reconstruction soit portée, ce qui renvoie à la 0041, encore proposée.
C ne demande rien.

**Même famille que la 0035**, comme le signale Jeremy. Toutes deux
posent la même question : faut-il une origine de plus, ou un axe de
plus ? La 0035 a répondu « axe calculé » pour la vérifiabilité, et elle
n'est toujours pas appliquée. **Il serait cohérent de trancher les
deux ensemble.**

## 5 — Ce qui reste vrai

- **Pas d'adoption, pas d'abonnement, pas de place dans la chaîne.**
  build123d reste la source de vérité ; aucune pièce YXOR ne sera
  décrite ailleurs que dans `parts/`.
- **Aucun scanner 3D.** Voir § 2 : cela ferme deux usages réels sur
  quatre, pas trois.
- **Aucune API trouvée** : même adopté, l'outil ne pourrait pas entrer
  dans `regenerer.py`, qui ne connaît que ce qui se relance en local.
  Une étape manuelle dans une chaîne régénérable serait une source de
  vérité parallèle.

## Déclencheur

**Les deux conditions ensemble :**

1. le test du § 2 passe **toutes** les portes binaires, et au moins le
   seuil « exploitable » sur E1 ;
2. **et** une pièce YXOR réelle a besoin d'une géométrie qu'on ne peut
   que **relever** — une pièce du commerce à loger, un objet physique —
   sur une source dont Jeremy a les droits (0045, § 4a).

Tant que la seconde condition manque, un test réussi ne change rien :
**il vérifie l'outil, il ne crée pas le besoin.**

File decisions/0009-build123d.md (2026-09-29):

# 0009 — build123d comme noyau de CAO paramétrique

Date : 2026-09-28
Amendée par : `0029-familles-de-licences.md` — CERN-OHL-S y était classée à tort comme non commerciale ; la conclusion de cette fiche est inchangée.
Espèce : close
État : amendée
Statut : acceptée

> **Manquement de procédure signalé.** Fiche écrite *après* installation,
> ce que la règle 5 interdit. Consigné plutôt que tu.

## Contexte

La phase 1 étape B demande de dessiner des pièces. Il faut un noyau de
CAO paramétrique pilotable en Python, puisque la règle 1 impose que toute
cote structurelle dérive de `H` et d'un ratio — donc soit calculée, jamais
saisie.

## Options examinées

| Option | Écartée pour |
| --- | --- |
| FreeCAD en script | Interface Python liée à l'application, difficile à exécuter sans affichage et à figer en version |
| OpenSCAD | Langage propre, pas Python ; pas de STEP natif, et l'export DXF y est indirect |
| CadQuery | Voir ci-dessous |
| **build123d** | Retenue |

### build123d plutôt que CadQuery

Les deux s'appuient sur **le même noyau géométrique**, OCCT, via le même
binding OCP. Le choix ne porte donc pas sur les capacités géométriques,
qui sont identiques, mais sur l'ergonomie et la trajectoire du projet :

- **build123d est l'évolution directe de CadQuery**, écrite par des
  contributeurs de CadQuery pour lever ses limites d'API. Il offre deux
  styles — *builder* (contextes `with`) et *algebra* (opérateurs sur les
  formes) — là où CadQuery impose son chaînage fluide.
- Le chaînage de CadQuery s'accommode mal du **code paramétrique long**,
  celui où une cote naît d'un calcul et non d'un littéral. C'est
  exactement notre cas : règle 1.
- build123d expose directement les **objets topologiques** (faces, arêtes,
  sommets), ce qui rend les vérifications automatiques possibles — et le
  projet en dépend : rien n'est présenté comme correct sans contrôle.
- L'export **DXF** est de première classe (`ExportDXF`, via `ezdxf`), avec
  l'unité déclarée explicitement. Vérifié, voir ci-dessous.

Ce n'est pas un jugement de valeur sur CadQuery, qui reste maintenu.

## Décision

### 1. Version épinglée strictement

```
build123d==0.13.0
```

Résolue **par pip le 2026-09-28** sur Python 3.14.4, pas imposée a
priori. Noyau : `cadquery-ocp-novtk 8.0.1.0.0`, soit **OCCT 8.0.1**.

**Motif de l'épinglage strict.** OCCT est un noyau géométrique C++. Une
montée de version peut modifier une tolérance de booléen, un arrondi ou
une tessellation **sans lever la moindre erreur** : la pièce sort
différente, et rien ne le signale. C'est exactement le mode de défaillance
déjà rencontré deux fois sur ce projet — les butées moteur prises pour
des butées d'articulation, et la pose de référence de la politique de
marche. Un faux silencieux.

Les 56 dépendances résolues sont notées dans `requirements.txt`.

### 2. Chaîne d'export vérifiée, pas supposée

`scripts/check_cad_toolchain.py`, **16 contrôles, 16 passés** sur une
pièce d'essai 40 × 20 × 5 mm percée Ø6 :

| Format | Contrôle | Résultat |
| --- | --- | --- |
| STEP | entité `LENGTH_UNIT = SI_UNIT(.MILLI.,.METRE.)` | conforme |
| STEP | relu, cotes 40 / 20 / 5 mm | conforme |
| STL | étendue des sommets 40 / 20 / 5 | conforme |
| **DXF** | **`$INSUNITS = 4`** (millimètres) | **conforme** |
| **DXF** | étendue du contour 40 × 20, perçage Ø6,0000 | **conforme** |

Le DXF conditionne toute la chaîne de découpe 2D, et CLAUDE.md exige
« millimètres, échelle 1:1 ». Un facteur d'échelle erroné ne lève aucune
erreur : il envoie une pièce au centimètre chez le découpeur. La
vérification est donc mesurée, et rejouable à chaque montée de version.

### 3. Licences

Vérifiées sur les 56 paquets installés : Apache-2.0, MIT, BSD, PSF,
ISC. **Ni GPL ni CERN-OHL-S** — la règle de CLAUDE.md est respectée.
(Sur le classement de CERN-OHL-S, voir la fiche 0029 : elle n'est pas
non commerciale, c'est du copyleft fort. La conclusion ne change pas.)

**Point de vigilance non résolu** : OCCT, le noyau C++ sous-jacent, est
publié par Open CASCADE sous LGPL-2.1 avec exception. Le paquet
`cadquery-ocp-novtk` déclare Apache-2.0 pour son propre code et
**n'embarque pas le texte de licence d'OCCT** : je n'ai pas pu vérifier
cette information depuis l'environnement. LGPL n'est ni GPL ni
CERN-OHL-S, donc la règle n'est pas enfreinte telle qu'elle est écrite,
mais le point mérite d'être tranché avant toute exploitation
commerciale — au même titre que la licence des poids (fiche 0003) et
celle des fichiers mécaniques amont (fiche 0001).

## Conséquences

- Monter `build123d` ou OCCT est une **décision**, pas une routine : elle
  impose de rejouer `scripts/check_cad_toolchain.py` et de comparer les
  pièces produites avant/après.
- La règle 1 devient applicable : les cotes se calculent depuis
  `params/anthropometry.yaml`, elles ne se saisissent plus.
- `build123d` vit dans le venv **du projet** (3.14). Aucun lien avec le
  venv amont : la règle des deux interpréteurs est intacte.

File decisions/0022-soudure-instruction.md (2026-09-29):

# 0022 — La soudure : instruction, sans décision

Date : 2026-09-29
Amendée par : `0031-torsion-par-section.md` — le facteur de rigidité en torsion n'est pas une constante : il se calcule par section (395x mesuré pour 40 x 60 en tôle de 2 mm, et non « un à deux ordres de grandeur »).
Espèce : historique
État : instruction
Statut : **instruction** — ne tranche rien, à dessein. Aucune règle du
projet n'est modifiée par cette fiche.

## Ce qui est affirmé, et par qui

Jeremy déclare avoir accès à la soudure. **À vérifier avant tout usage :**
quel procédé (MIG, TIG, baguette), quel matériau, qui soude, et sur
quelle épaisseur — ces réponses changent tout ce qui suit.

L'affirmation « MEVITA soude quatre pièces pour faire un volume » vient
de Jeremy. Elle n'est **pas vérifiée ici** : la fiche 0016 avait déjà
été corrigée pour une affirmation de ce genre avancée sans source.

## Ce que la fiche 0015 posait, et ce que la soudure lève

La fiche 0015 pose qu'**une pièce plate ne peut pas faire un volume**, et
en tire l'architecture en plaques et entretoises : les volumes s'obtiennent
par empilement, les efforts passent par des vis traversantes.

La soudure lève cette limite — localement. Un cordon rend deux tôles
**solidaires en tout point de leur jonction**, là où un boulon ne les
tient qu'en un point. La différence n'est pas de degré :

- **un assemblage boulonné** transmet l'effort par frottement sous la
  tête de vis, et cède en rotation autour du boulon dès que le couple
  dépasse ce frottement ;
- **un cordon de soudure** transmet sur toute sa longueur. Il fait des
  deux tôles une seule pièce.

## Ce que cela rouvre

**1 — Le caisson fermé, donc la rigidité en TORSION.**
C'est le gain principal, et il vaut d'être expliqué. Un U ouvert (deux
plaques et une entretoise) se tord très facilement : ses parois glissent
l'une par rapport à l'autre. Fermez le U par une quatrième face soudée,
et la torsion doit désormais cisailler les quatre parois. La rigidité
gagne **un à deux ordres de grandeur**, pour la même masse.

C'est ce que ferait un tibia ou un bassin : des pièces qui ne sont pas
chargées en flexion simple mais en torsion, parce que le pied porte loin
de l'axe de la jambe.

**2 — Le logement de roulement.**
CLAUDE.md interdit un logement de roulement obtenu par découpe : les
tolérances d'une découpe ne tiennent pas le serrement. Un **tube soudé**
en travers d'une plaque, puis alésé, donne un palier correct — c'est même
la solution classique. Aujourd'hui il faut un palier rapporté et boulonné.

**3 — Les angles autres que 90°.**
L'architecture en plaques et entretoises fait des angles droits sans
effort et tout le reste difficilement. Un cordon accepte n'importe quel
angle.

**4 — Les pièces massives locales.**
Un bossage, une chape, une oreille de fixation épaisse : aujourd'hui,
empilement de plaques et vis. Soudés, ils deviennent une seule pièce.

## Ce que cela coûte

**1 — C'est définitif, et cela contredit votre règle.**
CLAUDE.md pose : « assemblage démontable, aucun collage structurel ». Un
cordon n'est ni démontable ni reprenable : le défaire, c'est meuler.

**2 — La boucle d'itération s'allonge d'un ordre de grandeur.**
Le principal acquis de l'architecture actuelle est de pouvoir couper une
pièce en carton le soir même. Une pièce soudée suppose la tôle, le
déplacement, la disponibilité du soudeur. On ne valide plus une forme
dans la journée.

Et surtout : **on ne peut pas prototyper en carton une pièce soudée.**
Le carton ne se soude pas — la maquette ne vérifierait que l'encombrement,
jamais la tenue.

**3 — La déformation thermique.**
Un cordon chauffe très localement. En refroidissant, il se contracte et
**tire la tôle**. Deux plaques soudées d'équerre ne le restent pas : c'est
un phénomène systématique, pas un accident, et on le corrige par l'ordre
des cordons, des points d'accostage, ou un gabarit de bridage. Aucune de
ces techniques ne s'improvise.

Conséquence directe : toute cote **après** soudure est incertaine. D'où
l'usinage de reprise, qui suppose une machine qu'on n'a pas.

**4 — L'aluminium se soude mal, et il perd sa tenue.**
C'est le point le plus mal connu, et il est décisif ici :

- l'aluminium exige un poste **TIG à courant alternatif**, très au-dessus
  du poste à souder ordinaire ;
- les séries 6060 et 6082 se soudent ; la 7075 **ne se soude pas** ;
- surtout, un alliage à l'état **T6** (trempé, revenu) **perd son revenu
  dans la zone chauffée**. Un 6082-T6 y retombe autour de l'état T4, soit
  environ **la moitié de sa limite d'élasticité**, sur une bande de
  quelques centimètres de part et d'autre du cordon.

Autrement dit : **souder de l'aluminium affaiblit l'aluminium**,
précisément là où l'on a décidé de faire passer l'effort. On retrouve la
tenue par un traitement thermique complet, que personne ici ne fera.

L'acier n'a pas ce défaut, se soude au poste ordinaire — et pèse trois
fois plus.

## Où cela vaudrait la peine, et où non

| | Verdict | Pourquoi |
| --- | --- | --- |
| Caisson de tibia, de bassin | **oui, probablement** | la torsion est l'effort dominant, et c'est là que le boulonné est le plus faible |
| Palier de roulement | **oui** | un logement alésé n'a pas d'équivalent boulonné |
| Plaques de liaison, brides | **non** | le boulonné y fait aussi bien et reste démontable |
| Pièces d'apprentissage | **non** | on perd l'itération dans la journée, qui est tout l'intérêt |

## La question à trancher, que cette fiche ne tranche pas

> **Un sous-ensemble soudé peut-il être un composant, lui-même boulonné
> au reste ?**

Si oui, la règle du démontable tient **au niveau de l'assemblage** — on
démonte un caisson de tibia comme on démonte une pièce — tout en levant
la limite de la pièce plate **à l'intérieur** du caisson. Le robot reste
démontable ; ses organes deviennent des blocs.

Si non, la soudure reste hors du projet.

C'est la seule question qui compte, et elle vous appartient. Les trois
qui en découlent, si la réponse est oui :

1. Quel matériau ? L'acier soudable et lourd, ou l'aluminium léger qui
   perd la moitié de sa tenue au cordon ?
2. Comment vérifier une cote après déformation thermique, sans machine
   de reprise ?
3. Comment prototyper, puisque le carton ne se soude pas ?

Aucune de ces trois n'a de réponse évidente aujourd'hui.

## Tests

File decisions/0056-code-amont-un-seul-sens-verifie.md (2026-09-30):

# 0056 — Code sous le venv amont : un seul sens est vérifié

Date : 2026-09-30
Espèce : gouvernante
État : appliquée
Statut : **appliquée** — lot de cohérence validé par Jeremy le 2026-09-30 (~23 h), point 4. Ce qui est décrit est ce qui existe.
Remplace : `0004-code-amont-dans-le-depot.md`

## Pourquoi remplacer la 0004

Son § 3 affirme : « les deux sens sont désormais contrôlés à
l'exécution ». **C'est faux**, et CLAUDE.md le dit depuis le lot A du
2026-09-30. La fiche, elle, gardait l'erreur (audit de la nuit du 29,
C1 ; `docs/etat-des-lieux-2026-09-30.md` § 3.3).

## La décision

Les §§ 1, 2 et 4 de la 0004 restent **inchangés**, à savoir :

- `sim/upstream/` est le seul répertoire qui s'exécute avec le venv
  amont ;
- chacun de ses fichiers appelle `require_upstream_env()`, qui refuse le
  mauvais interpréteur ;
- la racine amont se lit dans `TODDLERBOT_ROOT`.

**Le § 3 est remplacé par ceci.** L'interdiction vaut dans les deux sens,
mais **un seul est vérifié** :

| Sens | Interdit | Vérifié à l'exécution |
| --- | --- | --- |
| `sim/upstream/` lancé par le venv YXOR | oui | **oui** (`require_upstream_env()`) |
| code YXOR lancé par le venv amont | oui | **non** : il tournerait avec MuJoCo 3.3.4 sans rien dire |

Le second sens ne repose que sur la discipline et sur le contrôle manuel
de CLAUDE.md (`python -c "import mujoco; print(mujoco.__version__)"`).

**Ce qui n'est pas décidé** : ajouter une garde symétrique dans le code
YXOR. C'était proposé par l'audit de la nuit du 29, et ce n'est pas fait.

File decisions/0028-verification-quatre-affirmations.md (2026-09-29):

# 0028 — Quatre affirmations d'un retour extérieur, passées au crible

Date : 2026-09-29
Espèce : historique
État : appliquée
Statut : **acceptée** — vérification, pas décision.

Quatre affirmations reposaient sur une source unique. Voici ce qui tient.

| | Affirmation | Verdict |
| --- | --- | --- |
| a | G-code Bambu non reproductible octet pour octet | **le signalement existe et dit exactement cela — mais il n'est corroboré par personne** |
| b | mode local sans aucune connexion sortante | **soutenue dans l'intention, pas dans sa forme absolue** |
| c | DIN 8580 rév. 2022 classe les procédés | **exacte** (déjà vérifiée, fiche 0026) |
| d | bd_warehouse : pièces build123d, Apache 2.0, vis et roulements | **exacte, et vérifiée en l'exécutant** |

## (a) Le G-code n'est pas reproductible

**Le rapport existe** : `bambulab/BambuStudio` **#11560**, ouvert le
**2026-07-15** par `codemakerIO`, intitulé *« CLI: slicing is not
run-to-run deterministic (survives CPU pinning + ASLR off) »*.

Il dit précisément ce qui était annoncé, et davantage. Les écarts ne sont
pas cosmétiques :

- marqueurs `M73` déplacés d'une ligne autour de mouvements identiques ;
- temps estimé à ±1 s ;
- ajustement d'arcs : `I-21.987 J-12.779` contre `I-21.669 J-12.504` ;
- **et une différence de MOUVEMENT réelle** : ralentissement de
  refroidissement à `G1 F13374` contre `G1 F12538` ;
- longueur de filament à ±0,08 mm.

**9 paires divergentes sur 15**, et cela **survit** à `taskset -c 0`
(un seul cœur) et à `setarch -R` (ASLR désactivée). Le rapporteur avance
l'ordre de sommation flottante variant avec la préemption des fils, et
note que `src/libslic3r/Thread.cpp` dimensionne le pool TBB sans qu'aucun
drapeau ne permette de forcer un seul fil.

### Ce qu'il faut en retenir, et la réserve

**Le signalement est un signalement.** Ouvert depuis **deux mois et
demi**, **zéro commentaire, aucun label, aucune réponse de l'éditeur**.
La cause avancée est l'hypothèse du rapporteur, pas un diagnostic établi.

Le classer « fait » serait refaire l'erreur de la fiche 0016. Il est
**crédible et précis** — il donne la commande, les versions
(v02.07.01.62 et v02.06.00.51), les plateformes, le taux d'échec — et
c'est tout ce qu'on peut en dire aujourd'hui.

**Ce que cela impliquerait pour YXOR, si cela se confirmait :** un
G-code ne pourrait pas servir de clé de cache ni de sortie contrôlée par
empreinte. Notre chaîne actuelle n'en produit aucun — nous découpons, nous
n'imprimons pas — donc l'impact est nul aujourd'hui. Il deviendrait réel
le jour d'une imprimante.

## (b) Le mode local

**LAN-only Mode existe**, documenté, et coupe le pilotage du nuage : la
machine ne dialogue qu'avec le réseau local, et la mise à jour de
micrologiciel se fait hors ligne par clé USB ou carte SD.

**Mais la formulation « n'initie AUCUNE connexion extérieure » n'est
établie par aucune source que j'aie trouvée.** Aucune capture réseau,
aucun engagement écrit de l'éditeur en ce sens. C'est une affirmation
qui ne se vérifie que par l'observation du trafic, et personne ne l'a
publiée.

**Et un fait qui compte davantage que la réponse :** en janvier 2025, une
mise à jour de micrologiciel a retiré l'accès au mode LAN ; l'éditeur est
revenu en arrière après la réaction de la communauté. Le mode existe donc
par **politique révocable**, pas par propriété d'architecture. Pour un
projet qui mise sur la durabilité de ses moyens de production, c'est la
nuance qui décide.

## (c) La DIN 8580

Vérifiée au tour précédent, fiche 0026 : `DIN 8580:2022-12` remplace la
révision 2003-09, six groupes principaux ordonnés par le devenir de la
cohésion de la matière. **La norme elle-même n'a pas été lue — elle est
payante.**

## (d) bd_warehouse — vérifiée en l'exécutant

Roue `bd_warehouse-0.3.0-py3-none-any.whl`, 140 ko.

| Point | Constat |
| --- | --- |
| licence | **Apache-2.0** — famille permissive, aucun problème (fiche 0029) |
| dépendance | `build123d>=0.11.1` ; **fonctionne avec notre 0.13.0**, testé |
| vis | `fastener.py`, 140 ko — normes **ISO 4762** et ASME B18.3 |
| roulements | `bearing.py`, 29 ko — **31 tailles**, un seul type `SKT` |
| autres | engrenages, joints toriques, brides, clavettes, filetages, pignons |

**Essai réel** : `SocketHeadCapScrew(size="M3-0.5", length=12,
fastener_type="iso4762")` produit un solide de 125,8 mm³.

### Deux constats qui pèsent sur l'adoption

**1. Il couvre un seul de nos trois roulements.**

| Notre référence | Dimensions | Dans bd_warehouse |
| --- | --- | --- |
| MR85 | 5 × 8 × 2,5 | **absent** |
| 623 | 3 × 10 × 4 | présent |
| 688 | 8 × 16 × 5 | **absent** |

**2. Un piège de cotation.** `length` est la longueur **sous tête**, pas
hors-tout : une M3 `length=12` mesure **15 mm** en tout. Mesuré pour 8,
12 et 16 : la tête ajoute 3 mm à chaque fois. Quiconque prendrait
`length` pour la cote hors-tout se tromperait de la hauteur de tête.

### Ce que j'ai fait du paquet

**Installé, exercé, puis retiré.** Le laisser installé sans l'inscrire
dans `requirements.txt` aurait créé exactement le piège que ce projet
traque : le code aurait pu s'en servir ici et la construction Docker
aurait échoué, sans que rien n'explique pourquoi. Le dépôt et
`requirements.txt` restent cohérents.

    .venv/bin/pip install bd_warehouse      # pour y revenir

### La question ouverte, que je ne tranche pas

Une cote venue d'`ISO 4762` est-elle d'origine `catalogue` — « fiche
technique d'un constructeur » — ou `litterature` — « publication
scientifique ou norme » ? Une norme ISO n'est ni l'un ni l'autre
exactement. La taxonomie de la fiche 0010 n'avait pas prévu le cas.

## Sources

- [BambuStudio #11560](https://github.com/bambulab/BambuStudio/issues/11560) —
  lu par l'API GitHub le 2026-09-29 : ouvert, 0 commentaire, 0 label.
- Documentation et retours communautaires sur le mode LAN-only.
- Roue `bd_warehouse` 0.3.0 depuis PyPI, métadonnées et modules lus,
  code exécuté avec le venv du projet.

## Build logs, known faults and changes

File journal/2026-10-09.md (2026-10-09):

# Journal du 2026-10-09

## Étude « familles de petits servos à bus » (aucune décision, aucun achat)

1. Question de Jeremy (2026-10-08) : « Pourquoi choisir du Feetech ? Car ce sont les actionneurs les moins chers du marché ? » Marché versé (`params/servos_bus.yaml`, 31 modèles, 7 familles, 63 sources) ; `scripts/servos_bus.py` → `docs/servos-bus-2026-10.md`.
2. Couple par franc (au blocage) : Hiwonder 2,50 N·m/10 CHF, Waveshare 1,54, Feetech 1,40, Dynamixel 0,49, HerkuleX 0,23 ; Kondo, Lynxmotion, Futaba : aucun prix convertible en CHF. Feetech n'est pas le moins cher au N·m ; couple continu publié seulement par HerkuleX et Lynxmotion (hors Feetech « rated »).
3. Lab léger à la marge 1,5 : AUCUNE famille ne tient les jambes ; le genou (14 rad/s) et la cheville (18 rad/s) manquent de VITESSE partout (le plus rapide assez fort : ~10 rad/s). À la marge 1,0 non plus.
4. Correction : le « Feetech en carton tient à marge 1,0 » de `docs/lab-leger-2026-10.md` reposait sur la vitesse inconnue du STS3250 ; avec sa fiche (7,9 rad/s), il ne tient pas. Rapport non régénéré (pas d'explorateur dans ce lot) ; correction écrite dans `docs/servos-bus-2026-10.md`.

## Lot « marcher lentement » (aucune décision)

1. Les vitesses requises de la marche viennent de 3 marches simulées (à 0,60 m : ToddlerBot 0,196, G1 0,547, T1 0,690 m/s) ; aucune à 0,10, 0,15 ou 0,30 m/s (null, INCONNU). La règle de l'explorateur garde à 0,15 m/s les marches rapides : mêmes vitesses qu'à 0,30 (soupçon vérifié, test).
2. Borne « marche la plus lente au moins aussi rapide » (`scripts/marche_lente.py`) : genou 14,1 → 4,6 rad/s (−67 %), cheville 18,2 → 2,5 rad/s (−86 %) de 0,30 à 0,15 m/s.
3. Plus haute vitesse tenue (donnée ToddlerBot, 0,196 m/s ; marge 1,5) : STS3250 oui, STS3215 non (couple ; à 1,0 la cheville en continu 0,996) ; RS05 et EduLite05 oui ; à 0,547 m/s (G1), RS05 et EduLite05 seulement à marge 1,0.
4. Règle : une donnée critique d'actionneur manquante (vitesse, couple continu) donne INCONNU, jamais « tient » (lab_leger, test sur le STS3250 sans vitesse). Conclusion « Feetech tient à marge 1,0 » retirée de `docs/lab-leger-2026-10.md`, raison écrite.

## Lot « robot entier, règle plus_lente » (aucune décision ; règle NON adoptée)

1. Explorateur : option `--regle-marche explorateur|plus_lente` (défaut inchangé ; test : tables et solutions identiques au commit cc340fd) ; `marche_lente.selection` partagée par les couples et la puissance ; aucune marche assez rapide → null, INCONNU.
2. `scripts/lab_leger_entier.py` (Lab léger entier, 0,10 / 0,15 / 0,196 m/s) : à la marge 1,5, RIEN ne tient (A ni B, carton ni alu). À la marge 1,0 : A carton (STS3250 aux jambes) dès H 0,45 → 0,826 m réels, 3,5 kg, ≥ 1 904 CHF, 16 J, 59 min ; à 0,196 m/s, H 0,65 → 0,689 m, 3,6 kg, 14 J ; B carton (RS05/EduLite05) H 0,55, 5,5 kg, ≥ 2 332 CHF, hauteur réelle inconnue (cotes EduLite05).
3. Ce que la règle changerait : rien pour le Lab actuel (0,850 m, 18,5 kg, ≥ 4 514 CHF) ni pour le Kit (3,05 kg, 1 178 CHF). Elle touche la fiche 0064 : attend une fiche de Jeremy.

## Lot « catégories absentes » (relevé seulement : aucun calcul, aucune décision)

1. Lu `docs/catalogue-composants-yxor.md` (non suivi par Git, laissé tel quel). Trois agents, mêmes règles que le marché des actionneurs (sources téléchargées et au registre, null si non lu, la plus prudente : fiche 0064) ; 309 sources ajoutées.
2. `params/capteurs.yaml` (17 produits : centrales inertielles, caméras, pieds, codeurs, LiDAR) ; `params/temps_reel.yaml` (Teensy 4.1, NUCLEO-G474RE, ESP32-S3, Pico 2 : CAN natif sauf Pico 2, transceiver à ajouter partout).
3. Compléments : `puissance.yaml` (chargeurs 12S : les modèles courants ne font PAS le 12S Li-ion ; les 12S réels sont des chargeurs de gros packs, Li-ion non cité) ; `calculateurs.yaml` (Hailo-8 M.2 : aucun revendeur du module seul) ; `actionneurs.yaml` (`marche.releve_2026_10_09`, 14 produits HORS du calcul : l'explorateur lit toujours 211 actionneurs).
4. Note périmée corrigée dans `actionneurs.yaml` : l'explorateur lit le bloc marché (211 actionneurs, 11 familles, compté). Test : sources au registre, relevé hors du calcul.
5. Suisse : seuls Bastelgarage.ch, Conrad.ch, Galaxus.ch et Distrelec (en partie) lisibles ; Pi-Shop, DigiKey.ch et Mouser refusés : la livraison DigiKey/Mouser vers la Suisse n'est pas lue.

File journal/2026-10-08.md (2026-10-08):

# 2026-10-08

## Lot 4a sexies : vérifications et corrections

1. **Décidé par Jeremy le 2026-10-08**, ses mots : « Je retiens le 12S pour les deux robots, sur les chiffres de l'explorateur du 7 octobre. » Fiche 0072 (complète la 0071) ; `puissance.yaml` (`tension_retenue`). Commit 17465bd vérifié poussé, site à jour.
2. Performance : solutions légères + variantes en parallèle (8 cœurs). Rapport IDENTIQUE à 17465bd (hors durée) ; 56 min / ~3 Go avant, 5 min 53 / < 1,7 Go tous processus après ; test ajouté.
3. Saut CORRIGÉ (`exigences_physiques.geometrie_saut`) : la course de poussée (25 % de la hauteur de hanche) et les angles (genou 130°) étaient incohérents ; même accroupi désormais : genou 37,0 rad/s à 0,50 m pour 10 cm (49,4 avant ; 34,2 était la hanche, même calcul). Aucune donnée publiée de saut de robot lue.
4. Coupure en variante (2,5 / 3,0 / 3,2 V, énergie 100 / 85 / 70 % PROPOSÉE) : saut 5 cm et gestes 2 m/s tiennent partout ; saut 10 cm nulle part (vitesse suffisante dès 3,0 V, couple du genou insuffisant).
5. Bornes PROPOSÉES (masses et cotes) dans `puissance.yaml` ; cellules de récupération et à marque masquée écartées (EVE 40PL, LG M50LT) : la 12S1P devient Molicel P50B, 210 Wh, 1,11 kg.
6. Place : BMS (29 %, borne) et contacteur (17 %, borne) dominent le volume électronique ; l'allongement du tronc, traité comme un robot proportionné (jambes comprises), emballe masse et hauteur (16–25 kg, 0,86–1,07 m) : hypothèse à revoir.
7. Module de décharge RobStride : seuil NON réglable (DIP 24 V : 27 V ; 48 V : 53,5 V) ; autres seuils « sur demande » ; la carte d'alimentation V1.3 a une décharge réglable par CAN (V_max + 6 V).

## Lot 4a septies : emballement, chaîne compacte, saut

1. **Décidé par Jeremy le 2026-10-08**, ses mots : « Je retiens une coupure à 3,0 V par cellule. » Réglage du BMS, réversible : `puissance.yaml` et index (règle 5) ; la fiche 0072 n'est pas réécrite.
2. Emballement corrigé : seul le tronc s'allonge ; couples lus à la JAMBE réelle, structure du tronc rallongé ajoutée, couples des jambes × hauteur du centre de gravité (Winter, PROPOSÉ) ; test qui voit échouer l'ancien comportement.
3. Chaîne à l'échelle (PROPOSÉ) : courant réel × 1,5 ; le plus petit, puis le plus léger, puis le moins cher. Chaîne COMPACTE (BMS à port commun, anti-étincelle, relais d'arrêt) ; relevé G : 27 produits, 33 sources. Corrigé en route : porte-fusible du même format que le fusible.
4. Lab, 250 Hz, meilleure RobStride : compacte 1,46 L, 11,5 kg, ≥ 3 955 CHF, 0,664 m réels ; industrielle 3,17 L, 16,2 kg, ≥ 4 395 CHF, 0,850 m (12 h 46 : 3,34 L, 17,8 kg, ≥ 4 487 CHF, 0,861 m).
5. Saut (`scripts/saut.py`) : seul, le 10 cm tient dès 40° d'inclinaison du tibia avec un RS06 au genou si M ≤ 21–24 kg ; à 30°, aucun RobStride n'est assez rapide. Dans le robot complet, il ne tient pas : au cas le plus défavorable, masse et facteur du tronc dépassent ce que le RS06 permet.
6. Inconnues restantes de la chaîne compacte : port commun et masse du BMS JBD, masse et courant de l'anti-étincelle, prix des absorbeurs.

## Lot « gamme YXOR et vision produit »

1. **Décidé par Jeremy le 2026-10-08**, ses mots : « La gamme YXOR comprend quatre modèles : YXOR Kit, YXOR Lab, YXOR Home et YXOR Pro ; YXOR Pro remplace ce que nous appelions YXOR final. Le projet est personnel, non commercial et open source. Le budget de chaque modèle est calculé selon ses capacités et ses contraintes. Je suis le premier utilisateur, et YXOR Kit est le premier modèle que je fabrique. Pour YXOR Lab, le saut est ramené à 5 cm. » Fiche 0073 (complète la 0069).
2. `capacites.yaml` : saut du Lab à 5 cm ; profil `final` renommé `pro` ; profils `kit` et `home` VIDES (à définir) ; code et tests suivis.
3. Explorateur (profil lab) : la meilleure RobStride tient désormais les 8 capacités calculées, saut 5 cm compris ; 250 Hz, chaîne compacte : 13,6 kg, ≥ 4 275 CHF, 0,715 m (13 h 47, sans saut : 11,5 kg, ≥ 3 955 CHF, 0,664 m) ; batterie 2P pour le courant de pointe.
4. `docs/vision-produit.md` (rédigé, PROPOSÉ) : modèles et publics, carte des capacités, « design unique » (même famille, pas mêmes pièces), éco-conception, Kit carton, licences à étudier, besoins du site.
5. Du premier prompt collé, non faits (objet perdu pour un projet non commercial, ou remplacés par le second) : `params/publics.yaml` et les questions réglementaires de vente.

## Lot « pilote SysML v2 » (aucune décision ; le YAML reste la source de vérité)

1. Outillage (agent, 13 candidats essayés dans le dossier de session) : OpenSysML (Open-MBEE, Apache-2.0, v0.9.2) PROPOSÉ, binaire sans Java, code 0/2 ; pilote OMG (EPL-2.0) en second avis ; écartés : spec42 (nom non résolu = avertissement), sysml2 (plante), SysON (pas de CLI), syside (propriétaire), sysml-2ls (archivé).
2. `scripts/sysml.py` engendre `model/yxor.sysml` (431 lignes) : axes, ensembles, capacités, gamme Kit/Lab/Home/Pro en variantes, 22 exigences de couple du Lab (τ ≥ a·M + b), autonomie, IA, traçabilité exigence → axe.
3. Valide pour les deux outils ; `tests/test_sysml.py` : à jour, valide, erreur vue ; validateur hors du dépôt (variable YXOR_SYSML), sinon la validation saute et le dit.
4. `docs/sysml-pilote.md` : recommandation PROPOSÉE « garder tel quel » (vue engendrée, sans extension) ; question ouverte : outil durable (fiche 0066, b).

## Lot « étude de YXOR Kit »

1. **Décidé par Jeremy le 2026-10-08** (prompt « Étude de YXOR Kit ») : modules successifs ; mêmes dimensions, taille et composants que le Lab ; « le carton le mieux adapté » ; outils du ménage (cutter, règle, équerre, pistolet à colle). Fiche 0074 (complète la 0073). Et : « Oui, télécharge durablement OpenSysML dans exports/ » : `scripts/outil_sysml.py` (deux empreintes, curl : la poignée TLS de Python expirait) ; le test SysML valide sans variable.
2. Profil `kit` : niveaux 0 à 4 PROPOSÉS (`capacites.yaml`, `modules`, contrôlés : axes de joints.yaml, niveaux connus) ; hypothèses dans `params/kit.yaml` (Lab recopié de l'explorateur, vérifié par test).
3. Marché carton (agent) : 33 produits, 18 qualités normalisées, 41 sources au registre (`params/cartons.yaml`) ; aucun ondulé de détail ne publie d'ECT ; DIN 55468-1 non lue.
4. Classement (critères PROPOSÉS : papier mono-matière, panneau, en Suisse ; e²/σ, masse, prix) : ondulé double premier ; BC 6 mm Modulor à peser ; Kapa éliminé (recyclage).
5. `scripts/kit.py` → `docs/kit-etude-2026-10.md` : option alignée 2,39 kg / 868 CHF au niveau 1, 3,11 kg / 974 CHF au niveau 3 ; Feetech tiennent le niveau 1 et « debout » ; la marche 0,3 m/s non (hanche, genou, cheville) : RS00 aux 10 axes, 5,74 kg, 1 634 CHF.
6. Réutilisation au Lab : 55 à 71 % du coût connu (alignée), 0 % (minimale) ; `docs/kit-yxor.md` : assemblage A/B/C (B PROPOSÉE), site actuel et besoins ; `docs/protocole-carton.md`.

## Lot « YXOR Kit : décisions et plans du niveau 0 »

1. **Décidé par Jeremy** (réponse écrite, ~19 h 55 ; le gabarit du prompt était vide) : « les niveaux 0 à 4 avec le niveau 3 limité à tenir debout en Feetech, la marche étant le passage au Lab ; l'option progressive […] bloc secteur 12 V aux niveaux 1 et 2 et la batterie au niveau 3 seulement, dans un boîtier ignifuge ; je garde le critère de recyclage ; assemblage B. Les servos Feetech sont la famille des petits axes de toute la gamme. » Fiche 0075.
2. Option progressive (`scripts/kit.py`) : 1,28 kg / 717 CHF au niveau 1, ≥ 3,05 kg / ≥ 1 178 CHF au niveau 3, 58 à 71 % réutilisés ; pire cas secteur 29,6 A : aucun bloc FERMÉ relevé ne suffit (GST220A12 : 15 A). Marché versé (`params/kit_marche.yaml`, 26 sources).
3. Explorateur, Feetech seul aux petits axes : le Lab passe de 0,715 m / 13,6 kg / ≥ 4 275 à 0,850 m / 18,5 kg / ≥ 4 514 CHF (genou RS06 à 0,07 N·m de sa limite à 0,65 m). Corrigé : la borne de coût comptait 0 CHF d'actionneurs dès qu'un prix manquait. Taille du Kit GELÉE à 0,65 m (question à Jeremy).
4. `parts/kit_niveau0.py` : 111 gabarits, 178 pièces + 44 cales, 40 A4 (tronc en tuiles), 19 logements STS3215/3250 prévus ; contrôles 2D et 3D vus échouer (le 3D était aveugle : intersection mal lue) puis 0 défaut ; hauteur 0,938 m (hanches empilées) ; rendu regardé. Cotes du STS3215 lues sur le plan Feetech (`hardware.yaml`, servos).
5. Notice `docs/kit-montage-niveau0.md` (engendrée, liste à réunir : 1,2 m² de carton, 38 vis M4, 38 écrous à frein, 76 rondelles) ; `docs/kit-yxor.md` mis à jour ; tests `test_kit_niveau0`.
6. Incident : le premier déploiement a échoué en silence (Coolify garde l'ancien site) : la pièce écrivait sa notice dans docs/, absent de l'image. Corrigé : en construction Docker, notice et contrôle 3D SAUTENT et le disent ; régénération vérifiée dans une copie au contenu de l'image.

## Étude « lab léger » (aucune décision)

1. Question de Jeremy : « Est-ce que l'étude et ce que nous avions déterminé pour YXOR Lab ne représente-t-il pas mieux YXOR Home finalement ? […] meilleure version de YXOR Lab plus optimisée et compatible avec YXOR Kit ? » Profil candidat `lab_leger` (PROPOSÉ) ; `scripts/lab_leger.py` → `docs/lab-leger-2026-10.md`.
2. Marge 1,5 : AUCUNE famille (Feetech, Dynamixel, RS05/EduLite05 ; alu 2 mm ou carton) ne tient la marche de 0,35 à 0,65 m (hanches, genou ; vitesse pour Dynamixel).
3. Marge 1,0 (celle des robots qui marchent, repère) : seul Feetech en carton tient, dès H = 0,60 m (0,695 m réels), 3,4 kg, ≥ 1 904 CHF, 13 J ; 70 % du Kit resservirait. Lab actuel : 0,850 m, 18,5 kg, ≥ 4 514 CHF, 87 J.
4. Ajouter 0,15 m/s à la grille commune change les besoins du Lab (tangage de cou 0,81 → 1,05 N·m, Lab infaisable) : niveau ajouté dans le processus de l'étude seulement.
5. Repères placés : ToddlerBot, Zeroth-01, Berkeley Humanoid Lite, LeRobot Humanoid ; Open Duck Mini v2, BRIDGE et Bumi absents du registre (non cherchés).

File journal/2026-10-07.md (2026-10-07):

# 2026-10-07

## Lot « explorateur, YXOR Lab » (phase 4a, aucune décision d'architecture)

1. **Décidé par Jeremy le 2026-10-07** (réponse à la question de Claude, le prompt laissait « [tes mots] » vide) : « J'adopte la loi allométrique mesurée, avec son intervalle comme bande d'incertitude ; H³ reste en mémoire comme borne pessimiste. » Inscrit dans `params/lois_masse.yaml` (`retenue`) ; appliqué à l'explorateur ; dimensionnement, grille et exigences gardent H³ : à appliquer.
2. Jeremy, même jour : « Non, Pareto maison » : pymoo NON installé, tri de non-domination dans le script.
3. `scripts/explorateur.py` : maximum par axe des tables a·M + b (3a, 3b ; marche cumulée sur les niveaux inférieurs), plus petit actionneur VÉRIFIABLE par famille, point fixe masse ↔ choix, faisable seulement aux b bas, central et haut ; INCONNU listé. Test du maximum vu échouer (somme).
4. Pertes constatées : les études de session du 2026-10-04 (ensembles 25/26/27/29, H_min) n'avaient jamais été versées. 26 (squelette v3) et 27 (fiche 0069) ont une source ; 25 et 29 RECONSTRUITS ; place par une règle simplifiée. PROPOSÉ, écrit dans le rapport.
5. Structure : facteur des plaques CALCULÉ par la CAO (jambe basse alu 3 mm, 450 g contre 97 g Winter : × 4,66), un seul segment, étendu à toute la structure.
6. Résultat : 114 688 solutions, 6 992 faisables ; front de 5, tous à H = 0,50 m (borne basse explorée). Meilleure : 25 axes, RobStride + Feetech, 14,2 kg, 2 521 CHF, 7 capacités.
7. Bloquants : couple continu des servos (Feetech, Dynamixel) inconnu ⇒ saisie et tête jamais décidables ; vitesses à vide Encos, Damiao, Unitree ; charge 10 kg infaisable (masse d'équilibre). Rapport `docs/explorateur-lab-2026-10.md` + .svg (rendu non regardé : aucun convertisseur SVG ici).

## Lot « explorateur, trois biais corrigés » (phase 4a bis, aucune décision d'architecture)

1. **Décidé par Jeremy le 2026-10-07**, ses mots : « Je valide : toute étude citée dans une décision ou réutilisée par un calcul vit dans le dépôt, avec un test. » Règle 9 de `CLAUDE.md`. Accès accordé à la transcription de session (« Oui, ce dossier seulement ») : études du 2026-10-03/04 retrouvées.
2. `scripts/taille_minimale.py` (hmin du 2026-10-04) : chiffres RETROUVÉS, 27 axes 0,613 m (ANSUR 0,642), 26 axes 0,664 m (ANSUR 0,809) ; le haut des fenêtres (0,640, 0,702) était un couple de l'ancienne méthode. L'ensemble 25 n'avait JAMAIS été calculé.
3. `scripts/structure_plaques.py` (etude_s du 2026-10-03/04) : étalonnage 0,92 sur la CAO (a) du commit 0b5e304 ; v3 pleine 3,92 kg, évidée 50 % + 2 mm 1,86 kg (1,85 alors). Commit c42a179, avant la relance.
4. Explorateur : place = taille minimale (avec écarts, ANSUR stricte rapportée) ; structure par ensemble, centrale évidée 50 % + 2 mm et haute pleine : six cas avec b ; profil cible (fiche 0069 ; buste à 3 axes, sol irrégulier → roulis de cheville : PROPOSÉ) ; H 0,50–0,90 m.
5. Changé : front 5 → 14 ; meilleure 29 axes (seule à couvrir tout sauf les doigts), RobStride + Feetech, H 0,60 → 0,771 m réels, 12,5 kg, 3 219 CHF (était 25 axes, 14,2 kg, 2 521 CHF). Structure ÷ 3,7 : marche seule 7,6 kg (était 11,7).
6. Effets : saut 20 cm devient faisable ; charge 5 kg et poussée 100 N plus durs (robot plus léger : équilibre, frottement). Réserve : tronc jusqu'à +132 % d'ANSUR (taille à 3 axes empilés), couples alors sous-estimés.

## Lot « profil du Lab, couples à la vraie hauteur » (phase 4a ter)

1. **Décidé par Jeremy le 2026-10-07**, ses mots : « Je retiens pour YXOR Lab : marche sur sol plat 0,6 m/s, sol irrégulier 2 cm, pente 5°, relevé sur le dos et sur le ventre, saut 10 cm, gestes 2 m/s, saisie 0,2 kg, poussée 20 N, buste en lacet seul, tête à 2 axes, visage sur écran. Réservé au final : inclinaison du buste, port de charges lourdes, course, mains à doigts. »
2. `params/capacites.yaml` : profils `lab` (ces mots) et `final` (fiche 0069, niveaux à balayer en 4b, buste à 3 axes) ; `capacites.py` les contrôle (test vu échouer : il a trouvé qu'une tâche réservée entière passait, corrigé).
3. Explorateur : couples lus à la hauteur RÉELLE (pas supérieur de la grille), structure à la hauteur réelle, itération jusqu'à stabilité (2 à 3 tours) ; réserve « sous-estimés » retirée.
4. Taille à 3 axes CONCOURANTS (PROPOSÉE, pour le final) : tronc −51 mm (RS05) ; 29 axes à 0,60 : 0,715 → 0,664 m réels. Aucun gain à 2 axes.
5. Résultat (profil lab) : front 14 → 6 ; meilleure 27 axes, RobStride + Feetech, 0,50 → 0,541 m réels, 9,8 kg, 2 633 CHF, couvre tout le profil (était 29 axes, 12,5 kg, 3 219 CHF : le buste à 3 axes n'est plus demandé).
6. Saisie et tête toujours INCONNUES (couple continu des servos) ; pente, sol irrégulier et visage non calculés. Le front reste à la borne basse (H = 0,50).

## Lot « marchés : batteries, calculateurs, cartes de bus » (données seulement)

1. **Décidé par Jeremy le 2026-10-07** (son prompt) : « Les deux robots, YXOR Lab et YXOR, fonctionnent entièrement sur batterie. Je préfère NVIDIA Jetson, mais je veux une comparaison chiffrée avec le Raspberry Pi 5 et ses cartes d'IA. » Fiche 0070 ; le calculateur reste une PRÉFÉRENCE.
2. `capacites.yaml` : tâches « autonomie » (10/20/30/60 min ; cycle 40 s de marche + 20 s debout) et « IA embarquée », PROPOSÉES, à confirmer.
3. Collecte par quatre agents, chaque source téléchargée : 57 batteries, 30 calculateurs, 29 cartes de bus ; 250 sources au registre (non redistribuables). Corrigé au versement : A123 50 A (0064).
4. Tension : RobStride 24–60 V (RS02, RS00), 15–60 V (RS05, RS06, RS03, RS10P), RS01 24–48 V ; Li-ion 10S–13S (13S : 54,6 V, 5,4 V de marge sous la coupure à 60 V), 14S trop près ; LiFePO4 10S–15S. Feetech 4–14 V selon le modèle.
5. CAN : 27 axes à 500 Hz, trame étendue 164 bits au pire bourrage : 4,43 Mbit/s, 7 canaux à 1 Mbit/s et 70 % de charge (5 à 100 %) ; 23 axes RobStride : 6. CAN-FD non documenté par RobStride.
6. Calculateurs : TOPS « AI Performance » Orin = INT8 sparse GPU + DLA (dense GPU : Nano 8 GB 33, NX 16 GB 38) ; Thor en FP4 sparse seulement ; Raspberry Pi 5 sans CAN ni consommation publiée.

## Lot « batterie, calculateur, bus et servos dans l'explorateur » (phase 4a quinquies)

1. **Décidé par Jeremy le 2026-10-07** (soir), ses mots : « Je confirme les tâches autonomie et IA embarquée, et le cycle de 40 s de marche suivies de 20 s debout. Pour YXOR Lab : autonomie 30 minutes, IA embarquée commande + vision. Pour YXOR final : autonomie 60 minutes, IA embarquée avec modèle de langage local. Je trancherai entre 12S et 13S sur les chiffres. » Fiche 0071 (complète la 0070) ; profils.
2. Versé : 3 rapports secondaires (lus avant commit) ; chaîne de puissance (38 produits), vérifications (Feetech, CANHUB, calculateurs) : 140 sources au registre. STS3215 C001 : 4 kg·cm nominal (fiche Feetech ; 6,5 chez les revendeurs, écarté, 0064). Ratio ANSUR profondeur de poitrine 0,147.
3. `scripts/systeme_electrique.py` + `params/puissance.yaml` (PROPOSÉ) : tension 12S/13S (vitesses à la coupure), énergie du cycle, batterie 21700, calculateur par niveau d'IA, bus, chaîne de sécurité, place dans le tronc ; branché dans l'explorateur (tests vus échouer).
4. Résultat Lab : aucune solution entièrement vérifiable (masses et cotes de la chaîne de puissance non publiées) ; meilleure RobStride 27 axes, ≥ 4 009 CHF (12S, 250 Hz), 12,2 kg, 0,595 m réels ; batterie 12S1P EVE 40PL 173 Wh, assez même pour 60 min.
5. Verrous : le saut de 10 cm est hors de portée des RobStride à la tension de coupure (31 rad/s en 12S, 34 en 13S, besoin 49) ; en 13S, aucun absorbeur de régénération du marché (module RobStride V1.1 à 53,5 V < 54,6 V).
6. Point 10 : Orin Nano 2 confirmé (NVIDIA, 8 Go, 78 TOPS de type non publié, S1 2027 ; enveloppe 40 W, pas 15 W) ; AI HAT+ 2 : 130 $ en janvier, 200 $ depuis juillet 2026.
7. Écart de Claude : un guetteur d'arrière-plan s'est reconnu lui-même par son nom et a attendu 20 min pour rien ; ensuite, attente par PID, puis en premier plan.

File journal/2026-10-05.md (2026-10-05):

# 2026-10-05

## Lot « stratégie : deux robots » (fiche 0069)

1. **Décidé par Jeremy le 2026-10-04** (cité par son prompt du 2026-10-05) : « Ok l'option c me semble très bien 👍 » et « et l'on peut d'ailleurs directement opter pour la stratégie de conception et de modélisation via des pièces hybrides ».
2. Fiche 0069 : deux robots, YXOR Lab et YXOR (noms provisoires, PROPOSÉS) ; gamme S/M/L/XL abandonnée (remplace la 0048) ; hybride avancé (remplace l'ordre de la 0050). Contenu détaillé de l'option C : rédigé par Claude, accepté par ces mots.
3. NON décidé : ensemble d'axes et hauteur du Lab (27 axes = proposition) ; la 0068 est à revoir alors ; définition d'une pièce « hybride » (la 0059 tient pour l'impression).
4. Inventaire de ce qui dépend de S/M/L/XL : 38 fichiers hors archives et journaux, rien modifié (terminal du jour). `CLAUDE.md` et `docs/decisions.md` signalent la 0069.

## Lot « marché des actionneurs » (phase 1, aucune décision)

1. Stratégie de Jeremy du 2026-10-05, REFORMULÉE par Claude (à faire confirmer) : explorer axes × actionneurs × taille, filtrer par la physique, tirer un front de compromis.
2. `params/actionneurs.yaml`, bloc `marche` (hors de `candidats`) : 183 actionneurs ajoutés, 27 candidats complétés, 10 familles logicielles (bus, protocole, logiciel). Collecte par six agents ; null si non lu, la plus prudente de deux valeurs (0064).
3. Grille de S et dimensionnement : sorties IDENTIQUES avant et après (vérifié). 342 fichiers lus inscrits au registre (`fournisseurs.yaml`), jamais versés.
4. Rapport engendré `docs/marche-actionneurs-2026-10.md` + graphique pointe/masse par famille (`scripts/marche_actionneurs.py`) ; test `test_marche_actionneurs`, vu échouer.
5. Trous : pointe 87, blocage 89, garantie 115, CH/UE 79, prix 72, fixations 73, STEP 37. Encos : site constructeur injoignable, données de revendeurs. Nouveau RS00 (6/17 N·m) annoncé sans manuel : référence à vérifier avant achat (0066).

## Lot « capacités en niveaux » (phase 2, aucune décision)

1. Principe de Jeremy (2026-10-05, ses mots, prompt du jour) : « Je ne veux plus "fixer" de budget, je veux calculer le budget en fonction des contraintes et de ce qu'il est réellement possible de faire » : budget et masse sont des SORTIES.
2. `params/capacites.yaml` : 14 tâches, 37 niveaux à balayer (PROPOSÉS par Claude ; gestes et poussée ajoutés, absents du prompt), articulations sollicitées, méthode de phase 3 ; sorties de l'explorateur (coût, masse, énergie de chute, énergie cinétique d'un membre).
3. `scripts/capacites.py` : contrôle des noms (règle 3 ; 6 noms à créer annoncés, dont ankle_roll) et rapport engendré `docs/capacites-niveaux.md` ; test vu échouer.

## Lot « exigences physiques » (phase 3a, aucune décision)

1. **Confirmé par Jeremy le 2026-10-05**, ses mots : « Je confirme la stratégie telle que reformulée par Claude, les capacités que j'ai cochées, et les niveaux proposés dans params/capacites.yaml » (statut mis à jour dans `capacites.yaml`).
2. Familles : 7 familles du corps couvrent le Lab (5–20 N·m) et ≥ 60 N·m ; Unitree n'a rien sous 23 N·m ; Feetech et Dynamixel seuls aux petits axes. PROPOSÉ (sans fiche) : invariant « une famille corps + une famille petits axes ».
3. `scripts/exigences_physiques.py` : saut, charge, saisie, relevé quasi statique, poussée, gestes, buste, tête ; H 0,50–1,40 m ; résultats rangés en τ = a·M + b, combinables par le maximum (`combiner`) ; hypothèses écrites (masse de référence ToddlerBot ∝ H³).
4. Masses minimales : poussée 100 N ⇒ M ≥ 20 kg (frottement) ; charge 10 kg buste droit ⇒ borne pessimiste de 55 kg à 0,60 m.
5. `params/references_simulables.yaml` : politiques de marche pré-entraînées pour ToddlerBot, T1, G1, Berkeley Humanoid Lite ; AUCUNE de course ; CPU pour faire tourner, GPU pour entraîner. Rapport `docs/exigences-physiques-2026-10.md` ; tests vus échouer.

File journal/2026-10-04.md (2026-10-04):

# 2026-10-04

## Lot « cheville à axes concourants (d) + factices ronds »

1. Étude (d), dans le dossier de session, rien de commité : croisement des axes à 30,5 mm (+6,2 mm sur ANSUR, +16,1 mm pour 10° de bascule au talon) ; cheville large de 118 mm ; roulis derrière le talon. Aucune décision.
2. **Factices ronds** (`parts/jambe_basse.py`) : disques aux diamètres réels (STEP), disque rotor libre, épaulement du RS02 (Ø78,5 puis Ø65), bandes en papier fort enroulées. Ils remplacent les boîtes carrées.
3. Balayage carton : genou −15..0 → −105..0°, tangage ±5 → −95..55°, roulis ±5 → ±70°, comme l'aluminium.
4. Plan A4 carton : 6 feuilles (32 pièces, bandes en papier comprises).

## Lot « cheville de S » (décision de Jeremy, fiche 0068)

1. **Décidé par Jeremy le 2026-10-04** (son prompt) : « Une masse faible au bout de la jambe compte beaucoup pour bien marcher. Des robots comme l'Unitree H1 ou MEVITA marchent avec 5 axes par jambe. Option c ». Fiche 0068, écrite avant application.
2. `ankle_roll` retiré de `joints.yaml` (déclaré `amont_non_retenus`, annoncé par le contrôle des noms), `configuration_S.yaml`, `squelette.yaml` (v3 : 26 DDL), `dimensionnement.JAMBE` (10 actionneurs de jambe).
3. Besoins de roulis de cheville de la marche de référence ÉCARTÉS, annoncés par la grille et le dimensionnement : hypothèse non vérifiée.
4. Écarts ANSUR : axe de cheville à 36,2 mm (S = 0,612 m), pied large de 96 mm (la chape enjambe le tibia).
5. `jambe_basse.py` : tibia porteur du RS00, chape du pied ; alu conforme ; plages genou −100..0°, cheville −85..55° ; 5 feuilles A4 (zone de planche portée à 215 mm).
6. Grille : v1 6,75 kg, H_max 0,804 m ; v3 9,80 kg, 0,684 m (modèle actuel). RS00 au roulis de hanche : la v3 tient désormais (0,603 m), test recalé. Banc : repli entre 2,10 et 2,40 N·m (protocole mis à jour).

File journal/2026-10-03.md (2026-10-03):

# 2026-10-03

1. **Squelette de S en v3** (hypothèse, 28 DDL) : `params/squelette.yaml` (ratios seulement) et `scripts/squelette.py` (MJCF simplifié, rendu regardé) ; masse 10,46 kg, égale au modèle de S ; test `tests/test_squelette.py`, vu échouer.
2. Constats sur le squelette : axes de hanche et de cheville superposés (169 contacts au repos), bras dans l'emprise des RS02 de hanche, avant-bras et main trop courts pour 3 RS05.
3. **Actionneurs factices** RS00, RS02, RS05 (`parts/actionneurs_factices.py`) : volume STEP, gabarit de perçage DXF par réglage. Cotes du RS05 relues sur son manuel (p. 10). Phase angulaire des trous : non publiée, à relever.
4. Carton plume 5 mm : les 23 trous M3 sont sous le minimum découpable (Ø5), à pointer puis reprendre au foret. Bord trou-contour : 0,55 à 1,8 mm, contre un voile de 6 mm : les plaques doivent déborder.
5. `controle_articulations` contrôle aussi les noms de `squelette.yaml` (gripper : nom provisoire, annoncé).
6. **Faisabilité « tout en 2D »** : `docs/faisabilite-2d-2026-10-03.md` (rapport, PROPOSÉ). Point dur : les liaisons à axes perpendiculaires (bassin, épaules, cou, chevilles).
7. Précédents lus : MEVITA (page, README, arXiv 2508.17684, tôle soudée aux hanches). Lynxmotion BRAT non lu (403).
8. FreeCAD : non installé ; rien installé.

## Lot « jambe basse en carton » (soir)

1. **Cheville** : écart ANSUR dans `squelette.yaml` (encombrement des RS00) : roulis 66,0 mm sous le tangage, axe du roulis à 39,7 mm du sol (ANSUR 24,3, axes confondus). Jambe +81,4 mm : S passe de 0,600 à 0,681 m si rien d'autre ne change.
2. **`parts/jambe_basse.py`** : pied (semelle S), liaison de cheville A/B/C à tenons et encoches, tibia en caisson, chape de genou, factices RS00/RS02 (carton). DXF par pièce, plan A4 multi-feuilles (`plan_decoupe.ecrire_planches_a4`), STEP d'assemblage, rendu regardé. Hypothèses dites : face de fixation du RS00, phase des motifs.
3. Carton plume 5 : 35 pièces sur 5 feuilles A4, 116 trous à pointer puis percer.
4. Alu 3 : contrôle réel du trou, du rayon rentrant et du voile (`controler`, vu échouer). Corrigé en route : dégagements en T, tenon central, C centrée. Reste : 2 motifs du RS00 à 2,6 mm (phase inconnue).
5. Masse des plaques alu : 460 g par jambe basse (dont la chape du genou, 78 g), contre 97 g de part du modèle (Winter) : × 4,8. L'hypothèse de 1,6 kg de structure ne tient pas.
6. Butées (joints.yaml, amont) : alu, genou libre −105..0°, tangage −95..55°, roulis ±70° ; carton (boîtes), genou −15..0°, tangage ±10°, roulis ±15°.
7. Densité de l'alu 2,70 g/cm³ (fiches GLEICH 6082 et 5754 lues, au registre) ; Reynolds inaccessible ce soir.

## Lot « conséquences sur S », point 4 (nuit)

1. STEP officiels RS00 et RS02 (dépôt RobStride/Product_Information, commit 3f0cae4, sans licence) : inscrits au registre, lus dans la session, jamais versés.
2. RS00 : la fixation du boîtier (6 × M3, Ø50, + 2 pions Ø3) est à l'AVANT avec la sortie ; l'arrière n'a que 4 × M3 sur Ø38. Mon hypothèse du soir était fausse. Phases relevées (boîtier 0°, sortie 30°, arrière 45°) dans `actionneurs.yaml`.
3. RS02 : 9 × M3 sur Ø73 à 6,06° ; la partie Ø78,5 fait 28 mm, pas une bride mince ; aucun taraudage à l'arrière.
4. cheville_A et cheville_B tiennent le RS00 par l'arrière : contrôle alu conforme (trou, rayon, voile), masse 451 g. Axe du roulis à 35,5 mm, jambe +77,2 mm (était +81,4).
5. Maquette carton : les coins des boîtes factices limitent le tangage et le roulis à ±5°.

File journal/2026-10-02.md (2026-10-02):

# Journal — 2026-10-02

## DFM tôle : trois rapports et sources primaires (11 h 23)

- Rapports Claude, Grok et ChatGPT versés tels quels par Jeremy dans `docs/sources/` (arrivés en cours de lot), inscrits dans `sources.yaml` comme secondaires, non vérifiés.
- Sources primaires LUES par Claude Code, dans `fournisseurs.yaml` : Reynolds AW-5754 (O/H111, 1,0 e) et AW-6082 (T6 : 3,5 e jusqu'à 3,0 mm, 4,5 e au-delà) ; PEM CLA-M3-1 (trou 4,75 +0,08, axe-bord 5,6, HRB 50 / HB 89 page contre HB 82 catalogue → 82) ; Böllhoff RIVKLE M3 = 5,0 mm (fût rond, matière non précisée) ; ISO 273 M3 moyen 3,4 via Engineering Hardware. Le PDF Böllhoff (tronqué) et reynoldseuropean.com (DNS) sont non lus, mais leur valeur est confirmée ailleurs.
- `operateur_cn_alu_3` : pliage R 5 déclaré → 5754 H111 (3,0 mm) PASSE ; 6082 T6 (13,5 mm, borne 3,0 → 4,5 e, 0064) NE PASSE PAS ; 6061 non lu. Bloc `dfm_litterature` (provisoire, PROPOSÉ : « retenues par Jeremy » sans ses mots) avec la source de chaque valeur ; aucun contrôle ne le lit.
- Semelle : aucun trou, fente, pli ni taraudage, donc ces règles sont sans objet ; pont le plus étroit 24,23 mm à S, au-dessus de 6 mm. 29 tests OK. Empreinte fbfac97841 → 42d6957a6b.

## Opérateur CN : précisions du 2026-10-02 (14 h 34)

- Source : réponses de l'opérateur CN à Jeremy, par message, le 2026-10-02 ; `declaration_operateur`, non mesurée. « 2 mm » = diamètre de la buse ; alu jusqu'à 8 mm ; « 5 axes » = fraiseuse (rayons d'outil inconnus) ; alliage des chutes et plieuse inconnus.
- `operateur_cn_alu_3` : trou découpé minimal 3,0 mm (« 2 ou 3 » → 3, 0064), qui prime sur les 4,5 de littérature ; `voile_min` déclaré 6,0 mm, qui remplace le garde-fou de 1,5 mm. Le site affiche maintenant ce réglage « coupable » (plus rien ne manque).
- CONTRADICTION consignée, non résolue : rayon intérieur minimal 2,0 mm déclaré contre un trou rond de 3 mm (rayon 1,5). Une pièce qui déclarerait ce trou comme son plus petit rayon rentrant serait refusée par `controler_pieces`. CLAUDE.md : « À CONFIRMER » mis à jour. 29 tests OK. Empreinte 42d6957a6b → e3133f08bc.

## Décision : jambes mixtes de S (19 h 50)

- DÉCIDÉ par Jeremy le 2026-10-02 : « Je pars sur l'option B. » Fiche 0067 : RS02 au roulis et au tangage de hanche et au genou, RS00 au lacet de hanche et à la cheville ; H_S 0,60, repli 0,55. Elle remplace la 0065, marquée en tête (texte non réécrit).
- `params/configuration_S.yaml` : répartition unique, hypothèse v3 (16 × RS05) et 60 g de structure par logement RS02 (hypothèse). Lue par `choix_actionneurs.py` (section 0 de la grille) et `controle_articulations.py`. Cotes de montage RS02 (spécifications, p. 10) et RS00 (manuel, p. 8) au catalogue ; le RS02 est déjà à sa valeur prudente (6 N·m).
- Configuration retenue à 0,60 m : v1 7,41 kg, T1, T2, T4, T5 PASS, 0,778 m portés ; v3 10,46 kg, PASS, 0,658 m ; limitante : tangage de cheville ; 1 432 / 2 901 CHF HT. `test_configuration_S` : RS00 remis au roulis de hanche en v3 → 0,576 m, refusé ; vu échouer avec la répartition ignorée.
- Modèle de masse : les 20 servos ToddlerBot du haut du corps (0,857 kg, CALCULÉS) sont retirés de la part en H³. S en RS00 homogène passe de 7,80 à 6,75 kg. Dans la grille homogène, RS05, X2-7 et AK45-10 passent de T2 FAIL à PASS, CyberGear et 5047-36 de T1 UNKNOWN à PASS. Les seuils du critère de banc (RS00 homogène) passent de 3,1 / 2,6-3,0 / 2,5 à 2,7 / 2,35-2,65 / 2,3 N·m ; `test_critere_banc` est recalé (2,8 → 2,5).
- Mis à jour : docs/decisions.md n° 7, README, protocole (une ligne : le banc ne couvre que le RS00), CLAUDE.md, anthropometry (libellé de S). 31 tests OK, 0 lien mort, 0 contradiction. Empreinte e3133f08bc → c0cc91c0ee.

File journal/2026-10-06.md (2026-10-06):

# 2026-10-06

## Lot « simulations de marche et de relevé » (phase 3b, aucune décision)

1. **LeRobot Humanoid EXISTE** (vérifié : API GitHub, billet du 2026-05-21) : 12 axes RobStride (RS00, RS02, RS03, RS05), cheville en liaison parallèle, Apache-2.0, 19,4 kg, politiques de marche ONNX. L'inventaire du 2026-10-05 disait le contraire : `references_simulables.yaml` corrigé.
2. Marches jouées sur CPU : ToddlerBot 0,19 m/s (tombe à 0,40 commandé), Booster T1 0,96 m/s, Unitree G1 0,80 m/s (Playground @ 86bfcd9, onnxruntime hors du dépôt). Couple enregistré = couple APPLIQUÉ à l'articulation (borne `actfrcrange`).
3. Relevé ToddlerBot (get_up, départ sur le ventre) : `sim/upstream/enregistrer_releve.py` ; `enregistrer_marche.py` écrit désormais ses métadonnées (.json).
4. `scripts/simulations_marche.py` : couples sans dimension τ/(M·g·H), référence prudente par articulation (0064), lignes a·M + b combinables ; 1 m/s couvert seulement à partir de H = 1,30 m (Froude max 0,285). Rapport `docs/simulations-marche-2026-10.md`, test vu échouer.
5. Le dossier temporaire de la session a été vidé : outils de clôture perdus (contrôle des liens recréé ; recherche de contradictions non recréée).

## Lot « loi de masse et outils de clôture » (aucune décision de méthode)

1. **Décidé par Jeremy le 2026-10-06** (réponse à la question de Claude) : « OUI, les verser » les outils de clôture. `scripts/controle_liens.py` et `scripts/controle_contradictions.py` (10 motifs reconstruits, sources citées), tests vus échouer ; ils ont trouvé l'en-tête périmé de la grille de S (0065 au lieu de 0067/0068), corrigé.
2. Rapports de méthodologie : Jeremy les déposera (sa réponse du jour) ; point 1 en attente.
3. Loi de masse : robomechanics/robot-dataset @ 3699af27 (sans licence : registre, hors dépôt), ajusté sur 31 bipèdes : b = 1,995 [1,814 ; 2,176] (IC 95 %), R² 0,946 ; humanoïdes complets seuls 2,273 [1,750 ; 2,796].
4. VARIANTE allométrique ajoutée (`params/lois_masse.yaml`, `exposant` de `dimensionnement.masse`, 3 par défaut, rien remplacé) ; rapport `docs/loi-masse-2026-10.md`. Oke et al. (résumé lu) : τ ∝ m·L vient de bipèdes quasi passifs en simulation (réserve écrite).
5. `scripts/source.py --liste` ne plante plus sur des pages à null.
6. **Écart de Claude** : les 4 rapports de méthodologie déposés par Jeremy ont été commités (`ed82d3b`, `git add -A`) AVANT d'être lus. Lus ensuite en entier : aucun extrait de norme ou d'ouvrage recopié ; inscrits au registre comme secondaires (`rapport_methodologie_*`).
7. Écarts relevés dans le rapport de Claude : masse ∝ L^2,12 contre 1,995 ici (sélection différente) ; build123d 0.12 annoncé, le venv a la 0.13. Les 133 références de ChatGPT sont des marqueurs sans lien, irrécupérables.

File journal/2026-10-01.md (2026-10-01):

# Journal — 2026-10-01

## Critères manquants du comparatif des familles — 00 h 05

**Décidé par Jeremy** le 2026-09-30, vers 23 h : les 9 poids et la règle
de décisivité sont validés ; il manque des critères essentiels ; il en
retient 7 familles, A à G. Source : son prompt du 2026-10-01, 00 h 05.

Ce lot **rédige et collecte**. Il ne recalcule rien, ne change aucun
poids et ne crée aucune fiche. Tout ce qu'il écrit est **PROPOSÉ** par
Claude Code (règle 7).

### 1. Proposition : `docs/criteres-manquants.md`

- **Règle du manquant, écrite AVANT la collecte** (§ 0) :
  - une valeur non publiée prend la **médiane** des candidats qui la
    publient, avec un drapeau « non publié » ;
  - si personne ne la publie, le sous-critère est **retiré** ;
  - un **contrôle de bornes** (0 et 5) dit si l'inconnue est décisive.
    Jamais de 0 par défaut.
- **24 sous-critères** en 7 familles, chaque niveau de grille défini par
  un fait. Trois seuils reposent sur des hypothèses marquées (H) :
  - la charge de référence du roulement, ≈ 150 N et 4,5 N·m ;
  - le porte-à-faux, 30 mm ;
  - l'épaisseur de la plaque, 3 mm.
- **Recoupements** :
  - C1 (masse installée) **remplace** la masse ;
  - F **fusionne** avec l'ouverture ;
  - B1 et E3 reprennent la réversibilité et les protections de la
    **robustesse** ;
  - C3 (banc) remplacera l'hypothèse k ;
  - A, D et G sont des **ajouts**.
- **D** reçoit ses deux options, sans choix : (a) critère pondéré, (b)
  indicateur hors score. Le biais « pénaliser qui publie plus » est
  rappelé : D5, les contradictions, est à normaliser ou à retirer.

### 2. Trois jeux de poids (proposés, aucun choisi)

`docs/criteres-manquants.md` § 3 : les jeux (i) 70/30, (ii) 50/50 et
(iii) fusion, chacun de somme 100, arrondis vérifiés par calcul.

- En (iii), les remplacements **héritent exactement** du poids remplacé :
  masse → C, ouverture → F, robustesse → résiduelle + B + E. Les ajouts
  purs (A, D, G : 15) sont pris au prorata sur les six critères sans
  recoupement.
- (i) et (ii) gardent des **doublons**, et le document le dit.
- Les poids actuels ne sont **pas** modifiés dans `criteres_selection.yaml`.

### 3. Collecte, non notée, et pertes cuivre

**Documents** : les 10 documents du registre 0030 utiles aux 6
candidats documentés. Les copies de travail sont dans le dossier
temporaire de session, et leur **sha256 concorde avec le registre**
(16 sur 16 retrouvés). Texte extrait par page (pypdf ; le xlsx est lu
comme XML, sans openpyxl, qui n'est pas installé).

**Relevé** : trois agents de lecture, deux candidats chacun, **36 clés
par candidat** (A à G), chaque valeur avec « document, p. N », ou null
avec « non trouvé dans … ».

- Assemblage et normalisation par Claude Code : nombres en nombres,
  unités en note.
- Quand aucune plaque ni dissipateur n'est publié,
  `C_plaque_nominal` est mis à null et les valeurs nominales passent en
  note.
- STS3250 : aucun document au registre, donc **tout est null**.
- Nouvelle section `collecte_criteres_manquants` d'`actionneurs.yaml`,
  marquée « collecte, non notée ». **Aucun script de notation ne la
  lit.**
- 5 motifs ajoutés à `origines.yaml`. Audit strict vert : 3 891 valeurs,
  dont 1 013 numériques ; 133 motifs, tous atteints.

**Taux de valeurs nulles** :

| Candidat | Nuls sur 36 | A | B | C | D | E | F | G |
| --- | ---: | --- | --- | --- | --- | --- | --- | --- |
| rs05 | 13 (36 %) | 4/7 | 3/6 | 0/2 | 0/4 | 1/5 | 4/4 | 1/8 |
| edulite05 | 16 (44 %) | 4/7 | 3/6 | 0/2 | 1/4 | 1/5 | 4/4 | 3/8 |
| dm_j4310_48v | 16 (44 %) | 4/7 | 3/6 | 2/2 | 0/4 | 2/5 | 4/4 | 1/8 |
| gim4310_10 | 14 (39 %) | 4/7 | 2/6 | 2/2 | 0/4 | 1/5 | 4/4 | 1/8 |
| x2_7 | 12 (33 %) | 2/7 | 1/6 | 2/2 | 0/4 | 2/5 | 4/4 | 1/8 |
| ak45_10_v3 | 27 (75 %) | 7/7 | 3/6 | 2/2 | 1/4 | 4/5 | 4/4 | 6/8 |
| sts3250 | 36 (100 %) | tout | | | | | | |

Au total, 134 valeurs nulles sur 252, soit **53 %**.

**Faits marquants, relevés et non notés** :

- **Chien de garde de communication désactivé en usine** : RS05 et
  EduLite 05 (`CAN_TIMEOUT = 0`), GIM4310 (0xCD désactivé). Valeur
  d'usine non trouvée pour le J4310 et le X2-7. **À régler avant la
  première mise sous tension au banc.**
- **Charges admissibles du roulement** : publiées seulement pour le X2-7
  (1 000 N radial, 250 N axial) et le GIM4310 (500 N, 125 N). Moment :
  nulle part.
- **Kt** : J4310 sans valeur chiffrée (formule seulement) ; GIM4310 **Kt
  incohérent** avec sa propre fiche (× 2,08) ; EduLite 05 Kt identique
  au RS05 malgré une autre réduction, copier-coller probable.
- **AK45-10** : le manuel au registre est celui de la série et ne cite
  jamais ce modèle.

**`scripts/pertes_cuivre.py`**, information et non critère. Il est
exécuté à H = 0,55 m, sur 12 actionneurs de jambe et 15 s de marche.

| Candidat | Kt utilisé | Pertes cuivre moyennes |
| --- | --- | --- |
| RS05 | 0,94 publié, par ampère efficace ; contrôle Kt × I_nominal = 1,60 N·m pour 1,6 publié | **30,2 W** |
| J4310 48 V | 0,729 implicite | 17,6 à 35,1 W (convention non précisée) |
| GIM4310-10 | 1,254 implicite (le publié est écarté) | 14,5 à 29,0 W |
| X2-7 | 0,80 publié | 6,4 à 12,8 W. Réduction 28:1 : moins de courant, mais les frottements ne sont pas comptés |
| EduLite 05, AK45-10, STS3250 | — | **non calculable** (R ou Kt manquant) |

### 4. Banc : sous-critères proposés

`docs/criteres-manquants.md` § 4 : **9 mesures** proposées pour le
protocole de banc, soit E1, E2, E3, B1, B2, B4, B5, G (Kt mesuré et
convention du courant) et C3 (rapport au besoin). Pour chacune :
l'instrument, et ce qu'elle tranche.

- **`docs/protocole-banc.md` n'est pas modifié.**
- **Proposé** : faire de **E1**, le chien de garde réglé et vérifié à
  vide, un **préalable de sécurité du § 1.3**. Trois documents sur trois
  qui publient la valeur d'usine le disent désactivé.

### 5. Ce qui ne peut pas être noté aujourd'hui

`docs/criteres-manquants.md` § 5, sous-critère par sous-critère, avec
les comptes de la collecte.

- **Notables et utilisables pour choisir S : 10 sous-critères**, soit A1,
  A2, B3, B4, C2, D1 à D4 et E1.
- **Inutilisables aujourd'hui** :
  - la famille **F** : 0 fait dans les documents au registre ;
  - **G1** : la convention du courant et Kt sont à mesurer ;
  - **E2** et le moment de A3 : personne ne les publie ;
  - A3, B1, B2 et C1 : médianes de 1 ou 2 valeurs, avant le banc.
- **STS3250** (100 % nul) et **AK45-10** (75 % nul) ne sont pas
  évaluables sur ces familles sans nouveaux documents au registre.

**Correction de comptes** : les familles A à G comptent **24**
sous-critères, et non 21 ; 10 sont utilisables aujourd'hui, et non 9.
Les messages des commits `90b2854` et `124e81c` portent les anciens
chiffres. Les documents sont corrigés.

### Clôture

- `regenerer.py` : code 0 ; **13 tests OK** ;
- audit strict : 3 891 valeurs, dont 1 013 numériques ;
- le comparatif régénéré ne diffère que par sa date : **rien nest- dépôt = site : **`e310c8797c`**, lu sur yxor.fr à 00 h 30.

---

## Lot E — 12 h 57

**Attribution** : tout ce lot est **PROPOSÉ par Claude (arbitrage,
2026-10-01)**, d'après l'audit externe ChatGPT du 2026-10-01 et la
collecte de la nuit. Il ne change aucun poids, aucune note retenue,
aucun statut de choix.

**Audit ChatGPT à verser : NON versé.** Le prompt annonce
`docs/audits/chatgpt-2026-10-01.md`, « texte fourni par Jeremy ». Ce
texte n'était ni joint au prompt ni présent dans le dépôt. Il n'est pas
reconstitué. Ce qui suit s'appuie sur ce que le prompt en rapporte.

### 1. Configurations du banc : une source unique

- **`params/banc.yaml`** (nouveau) : `banc.configurations`, 8
  configurations. Chacune donne ses modèles, le **nombre d'exemplaires
  PAR modèle** et le statut « composition NON DÉCIDÉE » :
  - les six du comparatif : 1, 2 ou 3 × vainqueur, deux finalistes,
    qualification, Feetech ;
  - les deux du budget : `rs05_x2`, `verification_j4310_x2`.
  - Les modèles qui dépendent du classement (`@S_gagnant`,
    `@S_finaliste_A`, `@S_finaliste_B`) sont résolus par le générateur.
    Rien de ce qui dépend du classement n'est figé.
- **Qui lit ce fichier** :
  - `selection_multicritere.py` construit les options du comparatif
    depuis lui ;
  - `budget.yaml`, pour la phase `banc` et l'option `verification`, y
    renvoie (`configuration: …`), et `dimensionnement.py` le lit. Les
    **coûts sont identiques** au tableau précédent (vérifié par diff) ;
  - `protocole-banc.md` § 2 ter porte une note datée de renvoi.
- **L'erreur de l'audit est corrigée dans le générateur.** La dispersion
  se **calcule** : au moins 2 exemplaires d'un même modèle. Avant, elle
  était déclarée « n ≥ 3 et même modèle ». C'est une modification datée
  dans `criteres_selection.yaml`. Effets, poids proposés inchangés :

  | Option | Avant | Après |
  | --- | ---: | ---: |
  | 2 × EduLite 05 | 3,15 | **3,25** |
  | 2 × Feetech | 0,75 | **0,85** |

  Les autres options ne bougent pas. La qualification reste en tête
  (4,30), avec le verdict « trop proches ».
- 3 motifs ajoutés à `origines.yaml` pour `banc.yaml`. Audit strict
  vert ; 136 motifs, tous atteints.

### 2. k en deux dimensions, pour information

`docs/choix-famille-actionneurs.md` § 3 ter, **engendré** par
`carte_k2()` dans `selection_multicritere.py`. Le k du J4310 et celui de
l'EduLite 05 sont balayés séparément, de 1,0 à 0,5 par pas de 0,05,
soit 121 cases. Le RS05 garde son blocage publié. Rien de ce qui
précédait n'est modifié dans le document : seules des lignes sont
ajoutées.

- **Choix à signaler** : que faire des **autres** candidats sans valeur
  en blocage (CubeMars, MyActuator) ? Deux cartes :
  - **« min »** (lecture prudente) : ils suivent le plus petit des deux k ;
  - **« 1,0 »** : CubeMars gagne dès que k EL05 ≤ 0,80, ce qui est un
    **artefact** de l'hypothèse la plus favorable qu'on lui accorde.
- **Carte « min »** :
  - **RobStride avec EduLite 05 : 71 cases** sur 121, dès que k EL05
    ≥ 0,70 (et partout pour k EL05 ≥ 0,85) ;
  - **RobStride avec RS05 : 36 cases**, pour k EL05 ≤ 0,65 et k J4310
    ≤ 0,90 ;
  - **Damiao : 14 cases**, seulement pour k J4310 ≥ 0,95 et k EL05 ≤ 0,80.
- **Frontières et borne plausible 0,619** :
  - EduLite 05 / RS05 : entre k EL05 = 0,70 et 0,65, **au-dessus de la
    borne**, donc dans la plage plausible. **k de l'EduLite 05 change la
    décision** ;
  - Damiao : k J4310 ≥ 0,95, à la limite haute de l'estimation en
    rotation (0,86–0,95) et au-delà de l'estimation au blocage
    (0,53–0,81).
- **Ne change pas le verdict.**

### 4. Deux scores, technique et approvisionnement (proposition)

`docs/choix-famille-actionneurs.md` § 3 quater, engendré. Ce sont les
**mêmes notes**, avec les poids décidés renormalisés par groupe :

- **technique**, somme 63 : capacité, continuité, robustesse, masse,
  ouverture, tension ;
- **approvisionnement**, somme 37, daté : coût, fiabilité, disponibilité.

**Le verdict retenu reste le score unique.**

| k | Technique | Approvisionnement |
| ---: | --- | --- |
| 1,0 | **CubeMars 4,16** > Damiao 3,90 > MyActuator 3,30 > EL05 3,13 > RS05 2,92 | **EL05 3,41** > RS05 3,00 > MyActuator 1,81 > Damiao 1,78 > CubeMars 1,59 |
| 0,9 et 0,8 | CubeMars > Damiao > … | idem |
| 0,7 et 0,6 | CubeMars > Damiao > RS05 > EL05 > MyActuator | idem |
| 0,5 | **Damiao 3,05** > CubeMars 3,02 > RS05 2,92 > … | idem |

**Lecture** : aucune famille n'est en tête des deux.

- Les fabricants les mieux notés **techniquement** (CubeMars, Damiao)
  sont les **derniers à l'approvisionnement**.
- La famille RobStride avec l'EduLite 05, gagnante au score unique,
  l'est surtout par l'**approvisionnement**.
- Le choix dépend donc du poids relatif des deux groupes, qui **n'est
  pas décidé**.
- Le classement technique dépend aussi de k, que CubeMars et Damiao ne
  publient pas au blocage.

### 3. OpenELAB : faits vérifiés le 2026-10-01

**(a) Garantie.** Source : `https://openelab.io/policies/refund-policy`,
lue en JSON et citée mot pour mot.

- « Effective Date: July 17, 2026 ».
- **Hors UE, dont la Suisse** : « 12-Month OpenELAB Limited Warranty […]
  from the date of delivery », en plus des droits légaux locaux.
  Réparation, ou remplacement gratuit.
- **UE** : garantie légale de 2 ans minimum.
- Exclusions : installation incorrecte, surtension, modification
  (soudure, firmware), etc.

**(b) Entrepôt et disponibilité du SKU DM-J4310-2EC-48V-V4.** Source :
JSON de la boutique, 13 h 04.

- 140,95 €, prix barré 172,95 €, `available: true`.
- **L'entrepôt de ce SKU n'est pas publié.**
- `available` ne distingue pas le stock de la précommande. La page HTML,
  qui porterait l'étiquette « Pre-order », est restée en erreur 429.
- **Politique d'expédition** (`/policies/shipping-policy`, JSON) :
  - stocks à Munich, Arlington et Shenzhen ;
  - commandes UE expédiées depuis Munich ou Shenzhen, selon le stock, en
    DDP ;
  - **hors UE, dont la Suisse : port de 19,95 € sous 300 €, droits,
    taxes et frais de douane à la charge du destinataire.**
- La description de la boutique donne la V4 à 3,5 / 12,5 N·m, comme la
  V1.2 du manuel. C'est un indice de « V4 = V1.2 », pas une preuve.

**Rangement** :

- nouveau champ `comparatif_S.dm_j4310_48v.garantie_revendeur`, **distinct
  de `garantie_mois`** (constructeur, toujours null) ;
- nouveau champ `disponibilite_revendeur`.

Le comparatif **ne les lit pas**. Deux motifs ajoutés à `origines.yaml` ;
audit vert.

- *Incident corrigé avant le commit* : l'insertion avait coupé le début
  de la ligne `distribution`. Elle a été rétablie, et le diff ne montre
  plus aucune ligne retirée.

**Score de Damiao à k = 1, sous les deux lectures, aucune retenue** :

| Lecture | Fiabilité Damiao | Score Damiao | Gagnant à k = 1 |
| --- | ---: | ---: | --- |
| garantie du constructeur seule (actuel) | 1 | **3,12** | RobStride avec EduLite 05 (3,23) |
| garantie du revendeur comptée | 3 | **3,42** | **Damiao** |

**⚠ Asymétrie.** Seule la garantie d'OpenELAB a été vérifiée. Celles de
Seeed (RobStride, MyActuator, SteadyWin) et des autres revendeurs ne
l'ont pas été. Compter une garantie de revendeur pour un seul candidat
favoriserait **celui dont on a vérifié le revendeur**. C'est le biais
« pénaliser qui publie plus », à l'envers.

La lecture (b) n'a de sens que si les garanties revendeur de **tous** les
candidats sont relevées.

### 5. Protocole : ajouts proposés, dans un document séparé

**`docs/protocole-banc-additions.md`** (nouveau). `docs/protocole-banc.md`
**n'est pas modifié**.

- **§ 0, préalable E1** : le chien de garde est lu, réglé non nul,
  vérifié à vide, et relu après chaque coupure. Le tableau de la
  collecte est rappelé : 3 valeurs d'usine publiées sur 3 sont
  « désactivé ».
- **§ 1-3, les 12 ajouts de l'audit**, chacun avec son *pourquoi*,
  expliqué pour un débutant, et ce qu'il faudrait écrire au protocole :
  - fusible DC près de la source ;
  - consignation et décharge du bus avant recâblage ;
  - polarité et masse ;
  - précharge ;
  - journalisation de Vbus ;
  - carter rigide ;
  - serrage spécifié ;
  - étalonnage et tare du capteur d'effort ;
  - position du thermocouple ;
  - arrêt sur perte de télémétrie ;
  - séquence couple nul → faible courant → sens → montée progressive.
- **Aucune valeur n'est fixée** (délai, calibre, couple de serrage,
  seuil) et **aucun achat n'est proposé** : les objets sont de
  l'outillage (règle b).

### Clôture du lot E

- `regenerer.py` : code 0 ; **13 tests OK** ;
- audit strict : 3 945 valeurs, dont 1 028 numériques ; 138 motifs ;
- documents engendrés stables (régénérés sans écart) ;
- dépôt = site : **`1c9a5a6a9f`**, lu sur yxor.fr à 13 h 12.

---

## Lot F — 13 h 18

### 1. BUG : 12 V annoncés pour une paire 48 V (introduit par le lot E)

**Le lot E (`429126e`) l'avait laissé passer.** `comparatif-banc.md`
disait : « L'option à deux finalistes tourne à **12 V** » pour EduLite 05
+ RS05, deux actionneurs 48 V. Le texte était engendré et passé à la
clôture du lot E sans être relu.

- **Cause** : en lisant `params/banc.yaml`, j'avais renommé la tension de
  la paire en `tension_paire`, mais le `return` d'`options_banc()`
  renvoyait encore `tension`. C'était la variable de boucle de la
  **dernière** configuration lue, Feetech, à 12 V.
- **Test d'abord** : `tests/test_tension_banc.py`, deux tests. Il a été
  **vu échouer** : « 12 != 48 : le document annoncerait 12 V pour une
  paire à 48 V ».
- **Correction** : la tension d'une configuration est **calculée** comme
  la tension commune des plages publiées de ses modèles. Elle n'est plus
  déclarée (les trois `tension_V` sont retirés de `banc.yaml`) ni prise
  par défaut. Le `return` renvoie la tension de la paire.
- **Toutes les configurations vérifiées** :
  - celles du comparatif, par le test : 1, 2 et 3 × EduLite 05 à 48 V ;
    paire et qualification à 48 V ; Feetech à 12 V ;
  - `rs05_x2` et `verification_j4310_x2`, à la main : 48 V. Aucun
    calcul ne lit leur tension.
- **Seule la phrase fautive change** dans le document. Aucun score ne
  bouge, car la note de coût lisait déjà la bonne tension par option.
- `calculer(cartes=False)` permet aux tests de sauter la carte k × k.

### 2. Fiche 0064 : la valeur la plus prudente

- **Décidé par Jeremy** le 2026-10-01. Ses mots : « Je valide la règle de
  retenir la valeur la plus prudente et sûre (marge de manœuvre) ».
- **Précision PROPOSÉE par Claude (arbitrage)**, marquée comme telle dans
  la fiche : la plus prudente est la plus défavorable au dimensionnement.
  Couple et vitesse : la plus basse ; masse, température subie et
  résistance : la plus haute.
- Ce qui **n'est pas** concurrent (§ 3 de la fiche, proposé) :
  - une valeur **remplacée** par le constructeur. J4310 : 306 g,
    « Weight corrected » en V1.4, contre 325 g antérieur, d'après
    l'audit externe et non vérifié ici ;
  - deux conditions de mesure différentes ;
  - une variante d'un autre produit ;
  - une lecture non vérifiée.
- **Limite relevée** : pour une **limite de protection**, le prudent est
  la plus **basse**. Le RS05 publie 145 °C et 135 °C ; le tableau
  proposé prendrait 145 °C. C'est à trancher, et c'est écrit dans la
  fiche.
- **Renvois remplacés** : « consigne de Jeremy » pour le RS05 à 1,6 N·m
  devient « fiche 0064 », dans `actionneurs.yaml:113`,
  `criteres_selection.yaml` (le P1 y est dit proposé par Claude et lancé
  par Jeremy) et `dimensionnement-par-actionneur.md`.

**Inventaire des cas où deux valeurs coexistent** (catalogue et collecte
du 01-10). **Aucune valeur n'est changée.**

| Cas | Valeurs | Retenue | Suit la règle ? |
| --- | --- | --- | --- |
| RS05, couple continu | 1,6 (manuel, plaque de 70 mm) / 1,8 (PDF, 150 mm) | 1,6 | **oui** |
| RS02, couple continu | 6 (site, prompt relayé) / 7 (PDF, deux fois) | 6 | **oui** |
| RS03, couple continu | 20 (p. 38) / 21 (p. 19) | 20 | **oui** |
| AK70-10, couple continu | 8,3 / 10 (résumé d'outil, non vérifié) | 8,3 | oui ; 10 n'est pas une valeur publiée |
| AK70-10, masse | 621 / 521 (résumé, non retrouvé) | 621 | oui ; 521 n'est pas publiée |
| J8006, vitesse à vide | 190 / « 390 rpm@24V » (coquille probable) | 190 | **oui** |
| RS05, couple de pointe | 5,5 / « 6 N.M » (couverture du manuel) | 5,5 | **oui** |
| X2-7, couple de pointe | 7 / 7,5 (tableau de calage) | 7 | **oui** |
| **AK80-9 V3, couple de pointe** | **22** (page produit) / borne MIT **±18** (manuel p. 42) | 22 | **NON**, si la borne MIT compte comme valeur de couple publiée |
| **EduLite 05, couple de pointe** | **6,0** (Seeed, README) / **±5,5** (exemple de code, manuel p. 56) | 6,0 | **NON**, si l'exemple compte (probable copie du RS05) |
| RS05, limite de bobinage | 145 °C (p. 12) / 135 °C (p. 34, 50) | — (le protocole lit 135) | **ambigu** : voir la limite de la fiche |
| J4310, masse | 306 / 325 | 306 | **remplacée**, non concurrente |
| GIM4310, couple continu | 1,63 (GDZ34) / 2,05 (GDS34) | 1,63 | autre produit, non concurrent |
| X4-36, couple de pointe | 34 / 30 (variante -E-L) | 34 | autre produit, non concurrent |
| RS02 masse, RS06 diamètre | 380 g / 405 g ; Ø82 / 88 (étude ChatGPT) | 380 ; Ø82 | lecture externe non vérifiée, non concurrente |
| continus en rotation et au blocage (RS05, RS02, RS06, RS03) | conditions différentes | les deux portés | non concurrents ; la capacité prudente prend le blocage |

Deux cas ne suivraient pas la règle, **selon qu'on compte la seconde
valeur comme publiée** : AK80-9 (pointe) et EduLite 05 (pointe). La
limite de bobinage du RS05 attend que la règle tranche le cas des
limites.

### 3. Fiche 0025 confirmée

**Confirmée par Jeremy** le 2026-10-01. Ses mots : « c'est bon je
valide, moi c'est bien accès au site depuis mon navigateur : mobile
iphone (safari) et mon pcportable (google) ».

- **En-tête seulement** (fiche 0054) : une ligne « Confirmée par » est
  ajoutée, avec la vérification faite sur iPhone (Safari) et PC portable
  (Google). Le corps est inchangé.
- La 0025 figurait parmi les décisions « attribution non établie » du
  2026-09-30, 23 h 43. **Elle a désormais une source.** Il restait au
  rapport de la nuit « jamais mesuré sur un appareil » : c'est fait, par
  Jeremy.

### 4. OpenELAB : pas de mail

**Décidé par Jeremy** le 2026-10-01 : on n'écrit pas à OpenELAB.

- **Restent non confirmés** :
  - le **stock réel** du SKU DM-J4310-2EC-48V-V4. `available: true` ne
    distingue pas le stock de la précommande, et l'entrepôt n'est pas
    publié ;
  - **« V4 = V1.2 »**. On n'a qu'un indice : la boutique donne la V4 à
    3,5 / 12,5 N·m, comme la V1.2 du manuel.
- **À vérifier sur le panier**, au moment d'un éventuel achat :
  l'étiquette « Pre-order », le délai annoncé, et la révision livrée.

### 5. Audit ChatGPT du 2026-10-01 : non versé

Aucun texte n'était collé sous le prompt du lot F. Conformément à la
consigne, `docs/audits/chatgpt-2026-10-01.md` **n'est pas créé** :
**non versé, à la demande de Jeremy**. Les lots E et F s'appuient sur ce
que les prompts en rapportent.

### Clôture du lot F

- `regenerer.py` : code 0 (64 fiches) ; **15 tests OK** ;
- audit strict : 3 942 valeurs, dont 1 025 numériques ;
- documents engendrés stables ;
- dépôt = site : **`42d52a31f3`**, lu sur yxor.fr à 13 h 24.

---

## Lot G — 13 h 35

### 3. La précision de la fiche 0064 et la règle par défaut (consignées ici)

La fiche 0064 n'est **ni réécrite ni remplacée** maintenant : la refonte
du dépôt réglera la forme des fiches. Ce qui suit la complète, avec
renvoi à la 0064.

- **Règle décidée par Jeremy** (0064) : « retenir la valeur la plus
  prudente et sûre (marge de manœuvre) ».
- **Précision (1)**, PROPOSÉE PAR CLAUDE et VALIDÉE PAR JEREMY : la plus
  prudente est **« la valeur la plus défavorable à la marge »**. Pour
  une **LIMITE** à ne pas dépasser, c'est la **plus basse**. Elle
  remplace la précision proposée dans la 0064 (« la plus défavorable au
  dimensionnement »), dont le § 2 relevait justement la limite.
- **Règle par défaut (2)**, PROPOSÉE PAR CLAUDE et VALIDÉE PAR JEREMY :
  en cas de doute sur ce qui compte comme valeur publiée, la valeur
  prudente est **retenue et notée, sans consulter Jeremy, sauf si elle
  change un verdict**.
- **Date de validation** : le prompt porte « VALIDÉ PAR JEREMY le
  [date] », un champ non rempli. Seule date établie : celle du prompt,
  2026-10-01 (13 h 35). La date exacte de la validation est **à
  confirmer** (règle 6).

### 1. Application aux trois cas (`params/actionneurs.yaml`)

| Cas | Avant | Retenu | En `autres_valeurs` |
| --- | --- | --- | --- |
| RS05, limite de bobinage | — (nouveau champ `protection_thermique_C`) | **135 °C** (manuel p. 34, 50) | 145 °C (manuel p. 12) |
| AK80-9 V3, couple de pointe | 22 N·m | **18 N·m** (borne du mode MIT, manuel AK V3.2.0 p. 42) | 22 N·m (page produit) |
| EduLite 05, couple de pointe | 6,0 N·m | **5,5 N·m** (exemple de code, manuel EL05 p. 56) | 6,0 N·m (Seeed, tables du manuel, README EDULITE_A3) |

L'ancien texte est conservé en commentaire daté. Audit strict vert.

### 2. Un verdict ou un classement change-t-il ? **Non.**

Comparaison du recalcul avant et après, sauvegardée au début du lot :

- **Familles** : scores, gagnants à chaque k, bascule (0,67/0,68),
  cartes k × k, deux scores, banc. **Tout est identique.** La règle
  par défaut (2) s'applique donc sans consulter Jeremy.
- **Ce qui bouge** :
  - **CubeMars, taille M** : 0,53–0,84 → **0,53–0,78 m**, avec la pointe
    de l'AK80-9 à 18. Le membre M est affiché, pas noté ;
  - **EduLite 05 homogène** : **0,54 m, inchangé**, car le roulis de
    hanche est limité par le continu et non par la pointe. Le lacet de
    hanche passe de 0,68 à 0,66 et la cheville de 0,58 à 0,56 ;
  - **configurations mixtes où l'EduLite 05 est la classe légère** : de
    0,02 à 0,03 m en moins (par exemple RS02 / EduLite 05 : 0,65 →
    0,63) ;
  - **« mixte EduLite 05 / RS05 » disparaît** (28 → 27 configurations).
    Les deux ont maintenant la même pointe (5,5), et le script ne calcule
    une paire mixte que si la classe lourde a une pointe **plus forte**.
- **Documents régénérés** :
  - `choix-famille-actionneurs.md` : 3 lignes ;
  - bloc du cadrage § 5 : « EduLite 05 1,8 / 5,5 » ;
  - tableaux de `dimensionnement-par-actionneur.md`, prose inchangée.
- **Le RS05 à 135 °C** n'entre dans aucun calcul. Le protocole de banc
  (§ 1.5) disait déjà 135 °C pour RobStride.

### Clôture du lot G

- `regenerer.py` : code 0 ; **15 tests OK** ;
- audit strict : 3 958 valeurs, dont 1 029 numériques ;
- documents engendrés stables ;
- dépôt = site : **`b325cb1a85`**, lu sur yxor.fr à 13 h 41.

## Diagnostic de refonte (13 h 48, lecture seule)

Demande de Jeremy (prompt du 2026-10-01, ses mots) : « on arrive à un
stade où il va falloir refactorer tout le repo […] auditer et
diagnostiquer […] comment tout réorganiser et réarchitecturer
l'arborescence du projet, quoi modifier, supprimer, fusionner, archiver,
créer ».

- Rapport : `docs/diagnostic-refonte-2026-10-01.md`. Inventaire calculé
  sur 163 fichiers suivis (39 634 lignes) ; constats ; architecture
  cible ; risques ; plan en lots R0 à R7.
- **Lecture seule respectée** : aucun fichier du dépôt n'a été modifié,
  déplacé ou supprimé, hors ce rapport et ce journal.
- **Tout est PROPOSÉ par Claude Code.** Rien n'est décidé, en
  particulier le sort de la notation (§ 3.4, options a et b) et la liste
  des fiches à archiver (32 en vigueur, 32 archivées).
- Répartition : gouvernance 56,8 %, choix 21,5 %, robot 12,3 %, site
  6,4 %, outillage 3,1 %. Le code qui produit de la géométrie fait 1 079
  lignes.
- Correction en cours de rédaction : un premier jet disait « CubeMars, si
  son k reste à 1,0 ». C'était faux : CubeMars ne gagne qu'avec des poids
  quelconques (34,7 % des tirages), jamais aux poids décidés. Corrigé
  avant le commit.

## Lot H — catalogue élargi et recalcul (13 h 58)

**Origine.** Prompt rédigé par Claude (arbitrage, comparatif actionneurs du
2026-10-01) ; **Jeremy lance ce lot**. Tout ce qui suit est PROPOSÉ, rien
n'est décidé. Aucune fiche, aucun poids, aucune grille, aucun nouveau script
de notation. Fiche 0064 et règle par défaut du lot G appliquées.

**Point 1, catalogue** (commit `f8d9190`). Trois agents de lecture ont fait
la collecte ; Claude Code a revérifié dans les copies de session les valeurs
qui décident (manuel RS00, fiche image du 4438-30, fiche PDF du 5047-36).

- **RobStride RS00** (S). Le PDF du 17-09, p. 38, publie deux versions :
  « nouveau » 6 / 17 N·m, 330 g ; « ancien » 5 / 14 N·m, 310 g. Le manuel
  260713 donne les valeurs « ancien », sans dire de quelle version il
  traite. **Retenu (0064, règle par défaut)** : 5 / 14 N·m, 330 g, blocage
  3,6 N·m (PDF p. 5), plage 24–60 V (la plus étroite), protection 135 °C
  (avertissement ; défaut à 145 °C). C'est une **enveloppe défavorable**,
  pas un produit unique. Seeed : 125 USD HT, en stock.
- **Le doute ne change pas le verdict.** Avec la version « nouveau »
  (6 / 17 N·m, sans valeur au blocage publiée, donc 6 × k), la famille
  RS00 gagne aussi de k = 1,0 à 0,5. La bascule vers RS05 n'arrive qu'à
  k = 0,3. Avec « ancien » cohérent (310 g), même verdict. Calcul hors
  dépôt (`variantes.py`, dossier de session). La règle par défaut
  s'applique donc **sans consulter Jeremy**.
- **HighTorque.**
  - **HTDW-4438-30** : 2 N·m nominal, 10 N·m « Locked-rotor », 237 g,
    24 V, 189 USD chez Seeed.
  - **HTDW-5047-36** : 4 / 16 N·m, 305 g, fiche de 2024 absente du site
    constructeur ; **prix null**, car la page Seeed « 5047-36 » vend
    désormais un autre produit.
  - **Le couple « Locked-rotor » est porté en POINTE**, comme le blocage
    du STS3250 et des Dynamixel ; jamais comme valeur « en blocage »
    continue.
- **Références** :
  - **CyberGear** : 4 / 12 N·m, 317 g, 24 V. Son manuel exclut l'usage
    commercial de la garantie, et OpenELAB le dit « EOL » dans un résumé
    non vérifié.
  - **AK40-10 V3.0** : 1,3 / 4,1 N·m, 190 g.
  - **XM430-W350** : pas de couple continu publié ; blocage 4,1 N·m à
    12 V.
- **« Référence ToddlerBot » pour le XM430-W350 : vérifié, inexact.** La
  classe est déclarée dans `toddlerbot_2xc.xml` (l. 19, `e337f3b`), mais
  aucune articulation ne l'emploie. Noté dans `fiche.note`.
- **« Famille B » et « famille C »** du prompt : ces étiquettes ne figurent
  nulle part dans le dépôt. Lues comme « HighTorque » et « référence ».
- **Registre 0030 : 19 documents ajoutés**, et non 23 comme le dit le
  message du commit `f8d9190` (erreur de compte, corrigée ici). OpenELAB,
  store.cubemars.com, robotis.us et la boutique HighTorque ont répondu
  HTTP 429 : rien n'en est retenu.
- **Robustesse**, par la grille inchangée :
  - RS00, 4438-30 et 5047-36 : 3 ;
  - AK40-10 : 5 ;
  - XM430-W350 : 1 ;
  - CyberGear : 0, car le constructeur ne nomme pas le type de train.

**Point 2, familles** (`4c09d55`).

- « RobStride, S = RS00 » (RS00 → RS02 → RS06).
- **HighTorque** (4438-30 → 5036-02-DNE → 6036-02-DNE). La gamme M et L
  existe **si** on lit le blocage publié (21 et 36 N·m) comme pointe. Le
  protocole commun est **déduit, pas déclaré** : `null`, continuité 3/5.

**Points 3 et 4, recalcul** (`cd2d184`). Poids, marge et règles inchangés.

- Tailles S, prudente puis optimiste, masse convergée à H_max :

  | Actionneur | k = 1,0 | k = 0,6 |
  | --- | --- | --- |
  | RS00 (prudente au blocage publié, ne dépend pas de k) | 0,67–0,75 m, 8,65 kg | 0,67 m |
  | J4310 48 V | 0,67 m, 8,39 kg | 0,55 m |
  | EduLite 05 | 0,54 m, 5,36 kg | 0,42 m |
  | RS05 (blocage publié) | 0,48–0,54 m | 0,48 m |
  | HTDW-4438-30 | 0,57 m | 0,45 m |

- Configurations mixtes : RS00 lourd + RS05 → 0,65 m, 7,6 kg ; RS00 lourd
  + EduLite 05 → 0,64 m, 7,7 kg. L'articulation limitante est le lacet de
  hanche, en classe légère.
- **Gagnant : RobStride avec RS00, à tout k de 1,0 à 0,3.** Il tient les
  ±50 %, et gagne 34,2 % des tirages quelconques à k = 1,0 et 52,6 % à
  0,6. Score 3,57, contre 3,23 pour l'EduLite 05 et 3,21 pour CubeMars à
  k = 1,0.
- **Deux scores** à k = 1,0 :
  - technique : CubeMars 4,16, puis Damiao et RS00 à 3,90 ;
  - approvisionnement : EduLite 05 3,41, puis RS05 et RS00 à 3,00 ;
  - **à k ≤ 0,9, RS00 est premier en technique.**
- **Carte k × k** : « Z » (RobStride avec RS00) sur les 121 cases, dans les
  deux lectures.
- **Banc** : « 2 × RS00 » en tête (2,85 ; 395 CHF TTC livré en CH, 439 en
  FR), classement robuste. **Composition NON décidée.** Le gagnant ayant
  une valeur au blocage publiée, aucune inconnue n'est plus décisive : le
  banc devient un banc de **vérification**.

**Réserves.**

- **La réserve de Jeremy** (« il manque des critères de comparaison
  essentiels », 30-09, ~23 h) **reste OUVERTE**. Le recalcul a été fait
  parce que le lot le demande, pas parce qu'elle serait levée.
- **RS00 dépasse l'intervalle de S [0,55 ; 0,60]** : il porte S avec une
  réserve de marge, au prix de la masse, puisque 12 × 330 g ≈ 4 kg
  d'actionneurs de jambe.
- **Prose non touchée**, donc deux endroits périmés :
  - la ligne de source du cadrage § 5 dit encore « le 30-09-2026 » au-dessus
    du bloc engendré ;
  - le paragraphe codé en dur « options × Damiao » de
    `docs/comparatif-banc.md` § 4 n'a plus d'objet.
- **Clôture** :
  - `regenerer.py` : 164 fichiers suivis, 138 motifs, 5 pages ;
  - 15 tests OK ;
  - audit strict : 4 627 valeurs (3 958 avant), 0 non qualifiée.

## Refonte R0 et R1 (15 h 25)

- Décisions de la refonte : DÉCIDÉES par Jeremy (prompt du 2026-10-01, ses mots : « Concernant les décisions de la refonte : oui à tout. »). Réponses aux 4 points : PROPOSÉES par Claude (arbitrage) ; validées en lançant le prompt, sans mots de Jeremy.
- R0 : tag `avant-refonte-2026-10-01` sur `39915ca`, poussé.
- R1 : 8 documents datés → `archive/docs/` par `git mv` (3 états des lieux, arbitrage, conclusion, contrôle de publication, choix-classe-S, exigences-P2).
- Chemins mis à jour dans README, CLAUDE.md, cadrage, criteres-manquants, estimation-thermique et .gitignore. Code, params, fiches et journal ne sont pas touchés : leurs mentions restent, en texte.
- Liens Markdown : 79 vérifiés, 0 mort. Empreinte inchangée : 7de57b6b21. 15 tests OK.

## Refonte R2 (15 h 40)

- Les 64 fiches et `index.md` → `decisions/archive/` par `git mv`, sans réécriture. `index_fiches.py` → `archive/scripts/` ; ses 2 fichiers de tests (4 tests) → `archive/tests/` ; retiré de `regenerer.py`.
- `test_regenerer_index` adapté à `controle_depot`. Vu passer, puis échouer quand la régénération ignore le contrôle (mutation annulée).
- `docs/decisions.md` : 15 décisions actives, avec l'auteur et la fiche archivée. 0002, 0009, 0018, 0030 et 0045 ont une attribution non établie : « à confirmer par Jeremy ». La liste des 8 fiches non attribuées y figure.
- Renvois `decisions/NNNN` → `decisions/archive/NNNN` dans 18 fichiers vivants (code, params, sim, README, CLAUDE.md, .gitignore). Journal, archives et diagnostic ne sont pas touchés.
- 106 liens vérifiés, 0 mort. 11 tests OK. 165 fichiers suivis. Audit strict : 4 627 valeurs.
- Empreinte 7de57b6b21 → b3df9a8605. Reste pour R5 : CLAUDE.md l. 181 cite encore `index_fiches`.

## Refonte R3, décision S (15 h 42)

- S DÉCIDÉ par Jeremy (« Je valide ta recommandation sur S. ») : RobStride RS00 sur 12 articulations, H_S 0,60 m, recommandation de Claude (arbitrage). Fiche `decisions/0065`, `docs/decisions.md` n° 7, `anthropometry.yaml` (S 0,60, repli 0,55).
- M0 de ToddlerBot comprend calculateur et batterie : DÉDUIT de l'arXiv 2502.00893v1 (p. 5 : composants pesés ; p. 6 : 3 484 g contre 3 454 g au MJCF ; p. 4 : tous deux dans le torse). 0,600 kg retirés de la part en H³ (p. 13, estimation « computer, battery, camera »). Ajout aux sources.
- Charge utile : 1,2 kg en masse fixe (PROPOSÉ par Claude). Masse à 0,60 m avec le RS00 : 7,40 / 7,80 / 8,20 kg pour 0,8 / 1,2 / 1,6 kg.
- RS00 à 0,60 m : PASS de T1 à T9. Couple efficace à 81 % du blocage, marge comprise ; pointe à 57 %. Relevé : 3,3 N·m au genou. Pas de FAIL, donc pas de calcul à 0,55 m.
- Archivés : selection_multicritere, criteres_selection, 2 fichiers de tests, 2 documents. « 10 °C sous la protection » déplacés dans `banc.yaml` ; les `@S_…` retirés. `actionneurs.yaml` intact.
- Créés : `exigences_S.yaml`, `choix_actionneurs.py` → `docs/choix-actionneurs.md`, `test_charge_utile` (vu échouer sans la masse fixe).
- 10 tests OK, 170 fichiers suivis, audit strict 4 346, 108 liens, 0 mort. Empreinte b3df9a8605 → e14d05a190.
- Reste pour R5 : la prose du cadrage (§§ 6, 9, 13) dit encore « famille non décidée ».

## Refonte R4, contrôles (16 h 02)

- Décision 4 de Jeremy (« oui à tout »). Archivés : audit_origines, nullites (script et yaml), controle_regles, enveloppes_actionneurs et son test, verifier_pages. `origines.yaml` réduit à l'amont (copie complète dans `archive/params/`).
- Créé `provenance_amont.py` : 1 123 valeurs ToddlerBot, le même compte que l'ancien audit. Il échoue sur une règle morte, un fichier absent ou un total nul. Test vu échouer (mutation).
- Créé `controle_articulations.py` : 30/30 moteurs, 30/30 articulations contre le MJCF amont, 5 listes de code, 12 colonnes de série (sautée et dite si absente). Test vu échouer (mutation).
- Gardé, par jugement : le contrôle du rayon intérieur minimal (CLAUDE.md, fabrication), déplacé dans `procedes.py`. Il protège les pièces.
- Site : la page traçabilité devient « Provenance amont » (`/provenance/`), sans nullites. Verdicts dessinable/coupable inchangés (vérifié : aucun « sans objet » ne jouait). La distinction « à mesurer / se déduira » est perdue.
- 17 tests OK, 5 pages, 175 fichiers suivis, 108 liens, 0 mort. Empreinte e14d05a190 → cf920bcbd2. CLAUDE.md et docs/decisions.md non touchés (R5).

## Refonte R5 (16 h 54)

- Verdicts des 13 fiches, DÉCIDÉS par Jeremy (« je valide toute tes recommandations, sauf pour la fiche 0023 que je passerais en B ») : A 0030, 0040, 0002, 0045, et 0009/0018 provisoires ; B 0034, 0026, 0033, 0023 ; C 0024, 0032 (en-têtes passés à « close »).
- Fiche 0066 « Règle d'achat » : (a) décision écrite et référence exacte vérifiée, (b) outillage à Jeremy, (c) jamais d'achat proposé par Claude. Elle remplace la 0027 (en-tête « Remplacée par »). `docs/decisions.md` : 18 actives, 4 conventions, 2 closes ; plus de section « à confirmer ».
- CLAUDE.md : nouvelle règle 5 ; « À lire d'abord » = README puis decisions ; journal en 10 lignes ; table des contrôles qui existent ; achat = fiche 0066. Retiré aussi : « Avancer sur une phase suivante », car les phases n'existent pas (0027). 343 → 284 lignes.
- README réécrit avec l'état courant (S = RS00, 0,60 m, 7,8 kg avec 1,2 kg de charge utile ; S/M/L/XL ; 12 DDL ; prochaine étape PROPOSÉE). Glossaire : 12 DDL en v1.
- Cadrage : version complète archivée (`archive/docs/cadrage-2026-09-30.md`), puis réduit à la vision et à la méthode (535 → 268 lignes). Renvois « cadrage § N » des fichiers vivants mis à jour, sauf `actionneurs.yaml`, laissé intact.
- Commentaires corrigés : budget.yaml (structure), hardware.yaml (imprimante), requirements.txt (« Phase 1 »).
- § 2.2 du diagnostic relancé : 10 contradictions cherchées dans 69 fichiers vivants, 0 trouvée (4 citations datées d'ancien texte écartées, nommées).
- 17 tests OK, 177 fichiers suivis, 113 liens, 0 mort. Empreinte cf920bcbd2 → 9e6d2923dd.

## Refonte R6, protocole du banc v2 (17 h 18)

- DÉCIDÉ par Jeremy : « Oui je valide les ajouts au protocole. » Et : « je suis seul sur ce projet » (pas de seconde personne). Les 7 mesures de travail isolé : PROPOSÉES par Claude (arbitrage), validées en lançant le prompt.
- v1 et ajouts archivés tels quels (`archive/docs/protocole-banc-v1-2026-09-30.md`, `…-additions-2026-10-01.md`). `docs/protocole-banc.md` v2 en liste de contrôle, §§ 0 à 7 ; l'outillage y est décrit par ses caractéristiques, jamais par un produit.
- Manuel RS00, relu : `canTimeout` 0x7028 (p. 46-47 ; aussi 0x200c, p. 21), défaut 0 = désactivé, reset à l'expiration (p. 28). Surtension 60 V (p. 28, 73), sous-tension 12 V. Énergie renvoyée en entraînement (p. 51). Plaque et ambiante du blocage à 3,6 N·m : non publiées. Courant de phase au blocage : non publié. Bornes 14 N·m / 16 A (p. 45-46) contre 17 / 23 (p. 20-21) : la plus basse est retenue.
- `banc.yaml` : seuil_thermique → rs00 (135 − 10 = 125 °C) ; une seule configuration, `rs00_x2`, NON DÉCIDÉE. `budget.yaml` : phase banc = rs00_x2, option J4310 retirée. `estimation_thermique.py` : lit sa propre constante J4310 (inchangé, 90 °C).
- INFORMATION, pas une décision : Jeremy aura peut-être accès à une impression 3D gratuite chez un ami (matière à sa charge), à confirmer ; l'usinage passerait par l'opérateur CN (matière fournie, chutes possibles) ; un achat d'imprimante est envisagé à terme. La fiche 0059 reste en vigueur jusqu'à confirmation.
- 17 tests OK, 178 fichiers suivis, 113 liens, 0 mort, 0 contradiction. Empreinte 9e6d2923dd → 18c6546821.

## Critère du banc outillé (17 h 31)

- PROPOSÉ par Claude Code (R6), recommandé par Claude (arbitrage) ; validé par Jeremy en lançant le prompt : plaque d'aluminium 90 × 85 mm (manuel RS00, p. 8-9), avec alliage, épaisseur et ambiante relevés à chaque session ; critère du § 4 outillé avant toute mesure.
- `choix_actionneurs.py` : le plus faible continu au blocage MESURÉ du RS00 (`alimente` : candidats.rs00.couple_continu_Nm.blocage) remplace les 3,6 N·m publiés, laissés intacts au catalogue. T1, T2, T4 et T5 sont relancés à 0,60 m et à 0,55 m ; verdict « S confirmé », « repli à 0,55 m » ou « famille rouverte », au § 6 de `docs/choix-actionneurs.md`.
- Seuils actuels : confirmé au-dessus d'environ 3,1 N·m, repli entre 2,6 et 3,0, rouverte à 2,5 et en dessous.
- `test_critere_banc` : mesures fictives dans un fichier temporaire (`params/mesures.yaml` non touché) ; 3 échecs quand la substitution est neutralisée. 23 tests OK.

## Refonte R7, vérification finale (17 h 31)

- Avant (`avant-refonte-2026-10-01`) → après : 164 → 179 fichiers suivis, dont 94 archivés (rien de supprimé). Lignes actives 40 912 → 26 177 (16 794 en archive).
- Gouvernance active : 89 fichiers et 23 376 lignes (57,1 %) → 19 fichiers et 12 456 lignes (47,6 %). Sans le journal (≈ 10 200 lignes, gardé tel quel) : ≈ 13 200 → ≈ 2 200 lignes.
- Robot 11,9 % → 18,7 % (lignes inchangées : 4 900) ; choix 21,8 % → 20,6 %. Fiches : 64 dans `decisions/` → 2 hors archive, 18 décisions actives dans `docs/decisions.md`. Tests 15 → 23 ; pages 5 → 5 ; liens 79 → 113, 0 mort ; 0 contradiction (10 cherchées dans 70 fichiers vivants).
- Diagnostic → `archive/docs/`. README : refonte terminée ; la suite reste PROPOSÉE. Étiquette `apres-refonte-2026-10-01`. Empreinte e0123be05d (inchangée par R7 : README et docs n'en font pas partie).

## État des lieux factuel (18 h 10)

- `docs/etat-factuel-2026-10-01.md`, en lecture seule : 9 commandes EXÉCUTÉES (toutes à 0), 23 tests OK, dépôt public, site = e0123be05d ; simulateur du navigateur non vérifié ; 10 fragilités, dont la série de marche hors Git dont dépendent 2 fichiers de tests sans `skipUnless`.

## Index des liens bruts (18 h 53)

- `scripts/liens_bruts.py` écrit `LIENS-BRUTS.md` : 183 fichiers suivis, groupés par dossier, liens bruts vers `main`. Appelé par `regenerer.py`, il ne réécrit le fichier que si la liste change (sinon le commit de l'en-tête rendrait le dépôt sale à chaque régénération) ; il saute en Docker et le dit. `test_liens_bruts` vérifié en échec avec une ligne retirée. 24 tests OK. Empreinte → a45cbd4b15.

## nginx : redirections relatives (19 h 00)

- Constat de 18 h 58 : une URL sans barre finale était redirigée en 301 vers http:// (nginx en clair derrière le proxy Coolify), puis en 307 vers https://. `absolute_redirect off;` ajouté à `nginx.conf`.
- `nginx.conf` n'est pas couvert par l'empreinte (`scripts/empreinte.py:49-50`) : le site garde a45cbd4b15, et le déploiement se vérifie par le comportement de la redirection.

## Simulateur vérifié contre le Python (19 h 14)

- DÉCIDÉ par Jeremy : « Je te confirme que le simulateur est fonctionnel » (vu dans son navigateur) ; « node est très utile et très utilisé, autant l'exploiter » (outillage, fiche 0066 b). Node v22.22.1, trouvé en `/usr/bin/node` (pas sous `~/.nvm`) ; `.nvmrc` ; ligne Environnement de CLAUDE.md ; aucune dépendance npm.
- Comparaison indépendante : `web/simulateur.js` exécuté sous Node (fonctions exposées en mémoire), contre la pièce à S et L (relevé restauré après chaque essai, `git status` vide) et `scripts/profil.py` à 0,55 m. 9 cotes et un contour de 233 points par hauteur ; pire écart 0,0001 mm (arrondi de r_ext à 0,55 m), pour une tolérance de 0,01 mm (cotes) et 0,05 mm (contour). Concorde.
- `tests/test_simulateur.py` : les trois hauteurs à chaque clôture. Vu échouer sur une copie temporaire faussée (r_ext × 1,002 : 0,016 à 0,026 mm, 3 échecs), puis passer ; il se saute en le disant sans Node. Convention 0023 mise à jour dans `docs/decisions.md`. 25 tests OK. Empreinte inchangée : a45cbd4b15.

## Opérateur CN : données déclarées (20 h 52)

- Source : réponses de l'opérateur CN à Jeremy, par message, le 2026-10-01 vers 20 h 45. Provenance `declaration_operateur`, non mesurée. Inscrit dans `hardware.yaml` : découpe laser ; saignée 0,5 mm compensée par l'opérateur ; rayon machine 2,0 mm ; ± 0,5 mm ; aluminium, laiton, titane, inox, céramique, 1 à 6 mm ; pliage R 5 mm ; écart entre pièces 10 mm ; tôle ≥ 2 m ; DXF, SVG, dpr ; alésage ; chutes et tôles pleines.
- `operateur_cn_alu_3` passe du jet au laser (même id) ; 4 réglages ajoutés, épaisseur à choisir. Aucun code ne compense la saignée (grep) ; le champ `saignee_compensee_par: operateur` l'interdit pour l'avenir.
- Contrôle du rayon : 10 réglages, aucune faute ; mais il ne voit que la règle de matière (0,5 × ép.), pas la limite de machine de 2,0 mm. La semelle à S en alu 3 mm passerait (creux R 53,57 mm). Le site affiche maintenant `operateur_cn_alu_3` dessinable (voile minimal manquant pour couper).
- À CONFIRMER : épaisseurs jusqu'à 10 mm, format « dpr », « 5 axes » (fraisage ou laser). CLAUDE.md mis à jour. Aucun réglage par défaut changé. 25 tests OK. Empreinte a45cbd4b15 → e837fc5a26.

## Rayon intérieur minimal : la limite de machine vérifiée (21 h 01)

- Règle : r_int_min = max(0,5 × épaisseur, `rayon_interieur_min_machine` du réglage), calculée en un seul endroit, `procedes.rayon_interieur_min`, appelé par profil.py, la pièce et les contrôles. `operateur_cn_alu_3` : 1,5 → 2,0 mm ; la limite de 2,0 mm devient un champ lu du réglage.
- Simulateur : même règle, la limite arrive par `simulation.fixes` dans la page (aucune valeur en dur dans le JS).
- Contrôles : réglage r ≥ max(…) (au lieu de l'égalité) ; pièce : `rayon_rentrant_min_mm` du relevé ≥ minimum du réglage. Vu échouer : alu 3 mm à 1,5 mm refusé par regenerer (code 1) ; copie du JS à l'ancienne règle refusée par test_simulateur. Semelle par défaut inchangée (2,5 mm, 3 lignes de relevé en plus).
- 29 tests OK. Empreinte e837fc5a26 → 7a239616bb : simulateur.js et le relevé (servis) ont changé.

## Garde-fous de littérature pour la tôle (21 h 14)

- `sources.yaml` : SendCutSend leçon DFM 5.2 (trou et pont ≥ 50 % de l'épaisseur, minimums testés) et FAQ (trou ≥ 50 %, rien sur les ponts) ; Protolabs (bord plié ≥ 4 × ép., trou ≥ ép., éléments à moins de 4 × ép. d'un pli déformés) ; metallservice.ch NON LU (connexion expirée, 4 essais, ECONNRESET) ; ISO 9013:2017 non lue, vocabulaire seulement. Pages lues par Claude Code ; sha256 du HTML ; aucun PDF dans le dépôt.
- `hardware.yaml`, réglages operateur_cn_* : `voile_min_litterature` = 0,5 × ép., PROVISOIRE (alu 3 mm : 1,5 mm ; autres : ép. non choisie) ; `voile_min` déclaré reste null. Rayons de pliage 5754 H111 et 6061 T6 : null, non lus. Le verdict « R 5 mm passe-t-il ? » n'est donc PAS établi.
- Bord plié minimal, règles divergentes :

| Source | Règle | État |
| --- | --- | --- |
| Protolabs | ≥ 4 × épaisseur | lu |
| SendCutSend | longueur propre à chaque matière (pages matière) | non lu, pas de ratio |
| « 2,5 × épaisseur » (prompt) | — | source non identifiée dans les pages lues |

- PROPOSITION (fiche 0064, la plus prudente) : 4 × épaisseur, soit 12 mm en alu 3 mm, jusqu'à ce que l'opérateur donne la sienne. Non appliquée. 29 tests OK. Empreinte 7a239616bb → fbfac97841.

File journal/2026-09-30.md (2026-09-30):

# Journal — 2026-09-30

## Backflip AI : vérifier un outil écarté, sans l'adopter

Un retour extérieur signale Backflip AI : de la CAO **paramétrique**
reconstruite depuis un scan, un STL, un plan 2D ou des photos. Si c'est
vrai, la phrase « les générateurs 3D par IA produisent des maillages,
pas des solides » est une généralisation tirée de trois outils.

**Cette phrase n'est pas dans le dépôt** : `grep` ne la trouve nulle
part. Je ne peux rien corriger ici, seulement constater qu'elle n'avait
jamais été tracée.

### Dans l'ordre

1. **La règle d'abord** — fiche 0045, écrite avant tout le reste :
   aucune géométrie amont ne passe dans un outil de reconstruction. Si
   cela arrive, le résultat reste `amont`. Elle vaut pour tous les
   outils de ce type. Elle est **non outillée**, et c'est dit. Une ligne
   a été ajoutée à CLAUDE.md, « Ce qu'il ne faut pas faire ».
2. **La vérification** — fiche 0046 § 1, sur six pages web :
   - quatre points sur cinq tiennent ;
   - **l'essai donne 50 crédits, pas 60** ;
   - **le point décisif, « paramétrique réel », n'est attesté que par
     l'éditeur** : pas d'essai indépendant lisible, et celui de Fabbaloo
     renvoie un 403 ;
   - pas d'API trouvée, ce qui ne prouve pas qu'il n'y en a pas ;
   - on ne sait pas quelles offres incluent Privacy Mode.
3. **Le protocole** — fiche 0046 § 2. La vérité de la semelle a été
   mesurée ce soir sur le STEP, à l'empreinte `7d61326025` :

   | Grandeur | Valeur |
   | --- | --- |
   | boîte englobante | 138,06 × 51,93 × 5,00 mm |
   | volume | 31 502,4 mm³ |
   | faces | 18 (8 plans, 10 cylindres) |
   | rayons | 4 × R 12,98 · 4 × R 2,5 · 2 × R 80,36 |

   La porte décisive : modifier l'extrusion de 5 à 3,5 mm dans Fusion,
   et retrouver 22 051,7 mm³. Seuils : **0,05 mm** pour « fidèle »,
   **0,5 mm** pour « exploitable » (ce second seuil est déduit, pas
   mesuré). Budget : quatre tâches Fast sur les cinq de l'essai.
4. **Les questions 4a et 4b** — instruites, pas tranchées.
   - 4a : un plan constructeur est un fichier fournisseur au sens de la
     0030. Sa reconstruction est une œuvre dérivée, comme chez
     McMaster, avec **un risque de plus** : l'envoi lui-même.
   - 4b : trois voies. La voie « nouvelle origine » est **la seule
     incompatible avec la 0045**, puisqu'elle ferait sortir l'amont de
     l'audit.

### Une nuance au retour de Jeremy

« Trois usages sur quatre supposent un scanner » : j'en compte
**deux**. Photo to CAD ne demande qu'un téléphone, d'après l'éditeur,
et Drawing to CAD qu'un plan.

### Ce qui n'est pas fait

- Rien n'a été téléversé, et le test n'est pas lancé.
- `experiences/` et `comparer_reconstruction.py` ne sont que proposés.
- La 0045 **ne vérifie rien** d'elle-même.

---

## Lot A de l'audit de la nuit : faire dire la vérité aux contrôles

Source : `docs/etat-des-lieux-2026-09-29-nuit.md`, § 8. Principe posé par
Jeremy : **quand un document promet un contrôle qui n'existe pas, on
corrige la promesse, on ne construit pas le contrôle.** Aucune fiche,
aucun contrôle nouveau. Un commit par point.

### Point 1 — la licence : CC BY-NC-SA, pas BY-NC

Ligne exacte, `~/upstream/toddlerbot/README.md:167` au commit `e337f3b` :

> The ToddlerBot design (Onshape document, STL files, etc.) is released
> under the License: CC BY-NC-SA (https://creativecommons.org/licenses/by-nc-sa/4.0/),
> which allows you to use and build upon our work non-commercially.

Corrigé à deux endroits :

- **CLAUDE.md** : le paragraphe disait « CC BY-NC : c'est la première
  famille, et non la seconde ». C'était faux. NC-SA appartient aux
  **deux** familles.
- **fiche 0001** : « Creative Commons non commerciale » devient « CC
  BY-NC-SA 4.0 ». La correction est datée dans le corps de la fiche. La
  fiche dit aussi la conséquence de SA : aucune géométrie amont dans une
  pièce YXOR.

La question des **valeurs numériques extraites** est notée comme
question juridique ouverte, **sans avis**.

Non touché : le README dit encore « Creative Commons non commerciale ».
C'est incomplet sans être faux, et c'est hors du périmètre demandé.

L'insertion déplace le texte de la 0001. Les renvois « ligne 24 » et
« ligne 36 » des fiches 0010 et 0011, déjà décalés (audit de la nuit),
le sont un peu plus. Ils ne sont pas corrigés, parce que cela
reviendrait à toucher à l'immuabilité des fiches, qui est hors lot.

### Point 2 — CLAUDE.md décrit ce qui existe

- **« Les deux sens sont vérifiés à l'exécution »** est devenu : un seul
  sens est vérifié (`sim/upstream/` refuse le mauvais interpréteur), et
  le code YXOR ne vérifie rien. Aucune garde n'a été ajoutée : c'est le
  principe du lot.
- **« `regenerer.py` peut le refuser »** est devenu : `etat_procede`
  calcule le verdict et le site l'affiche, mais **rien ne le refuse**.
- **`coupable` est inerte, et c'est désormais écrit.** Je l'ai vérifié
  en relisant `pages.etat_procede` (l. 178-200). Le verdict ne regarde
  que la saignée et le voile, filtrés par `besoins_procede`. Or une pièce
  qui se construit ne déclare que son épaisseur et son rayon minimal.
  `coupable` ne dépend donc plus que de la machine connue. **Cela
  corrige la passation**, qui disait « vrai dès que la pièce se
  construit » : un réglage sans machine (`operateur_cn_alu_3`) reste non
  coupable.
- **Chiffres d'audit retirés** : « 5 pages, 92 fichiers, 62 motifs,
  682 numériques » (des exemples devenus faux), « 755 sur 1431 »
  (renvoyé au journal du 2026-09-29, l. 1470, qui le porte) et « 1121
  cotes ». Ils sont remplacés par « N » ou par un renvoi. Il ne reste
  aucun nombre d'audit dans CLAUDE.md : vérifié par un grep des nombres
  à trois chiffres.

### Point 3 — l'empreinte couvre requirements.txt et le Dockerfile

**L'empreinte change, et c'est attendu** : `7d61326025` devient
`5d24300b2e` à ce commit. Elle changera encore aux points 4 à 7, qui
touchent `scripts/` et `params/`. Le site affichera l'ancienne valeur
jusqu'au prochain déploiement.

**Le Dockerfile a dû être touché** : `COPY Dockerfile .` dans l'étage
constructeur. Sans cette ligne, l'image n'a pas le Dockerfile et
calculerait une autre empreinte que le poste. Ce serait le défaut du
2026-09-29 (« un signal qu'on ne peut pas confronter ne signale
rien »), recréé à neuf. Un fichier absent **lève une erreur** au lieu
d'être sauté : un saut muet donnerait justement cette divergence sans
bruit.

**Test** : `tests/test_empreinte.py`. C'est le premier test du dépôt,
lancé par `.venv/bin/python -m unittest discover -s tests -v`. Il n'est
**pas** branché sur `regenerer.py`, ce qui en ferait un nouveau contrôle.

- Avant la correction : **FAILED** — `'a247541818' == 'a247541818' :
  requirements.txt ignoré par l'empreinte`.
- Après : **OK**.

### Point 4 — regenerer respecte le code de retour d'index_fiches

`regenerer.py` (anciennement l. 399) appelait `index_fiches.main()` sans
en lire le retour. C'est désormais `if index_fiches.main() != 0: return
1`, comme les deux contrôles voisins.

**Test** : `tests/test_regenerer_index.py`. Il simule un échec
d'`index_fiches.main` et construit le site pour de bon
(`--site-seulement`).

- Avant : **FAILED** — `0 == 0 : index_fiches a échoué, regenerer a
  rendu 0`.
- Après : **OK** (10 s).

### Point 5 — index_fiches lit toutes les lignes « Amendée par »

`entete()` renvoie désormais la **liste** des amendements. L'index les
affiche séparés par `<br>`.

**Vérifié sur la vraie fiche** : la ligne 0015 de l'index porte de
nouveau les deux amendements, **0042** et **0016**. C'est la **seule
ligne de l'index qui change** (`git diff --stat` : 1 ligne), ce qui
confirme qu'aucune autre fiche n'en avait deux.

**Test** : `tests/test_index_fiches.py`, sur une fiche d'essai à deux
amendements.

- Avant : **FAILED** — `'0016' not found in '0042-premiere.md — premier
  amendement.' : le second « Amendée par » est perdu`.
- Après : **OK**.

Non touché : la réciprocité des renvois (0012 ← 0034, 0020 ← 0033, 0028
← 0035). La corriger demanderait d'écrire dans ces fiches ou d'ajouter
un contrôle, et les deux sont hors lot.

### Point 6 — ratios_ansur : Drillis & Contini figées

**Retrouvables avec leur source : oui.** `git show
9c7eef5:params/anthropometry.yaml`, bloc `ratios`, dernière version avant
`fc05929` (ANSUR II). Chaque ligne y porte `source: "D&C fig. 4.1"` et
`verifie: false`. Deux valeurs étaient dérivées par soustraction :
`tronc_hauteur` et `cou_hauteur`. Les 14 valeurs sont figées dans
`DRILLIS_CONTINI`, avec leur provenance et la réserve « graphique, non
vérifiées ». Le script ne lit plus du tout `anthropometry.yaml`.

**Recoupement** : les écarts affichés redeviennent ceux que la fiche 0034
avait publiés au moment du remplacement (hauteur_hanche −2,9 %, tibia
−7,9 %, pied_longueur +0,9 %, largeur_epaules −10,1 %). La comparaison
perdue est retrouvée à l'identique.

**Test** : `tests/test_ratios_ansur.py`. Il lit les CSV ANSUR locaux, qui
sont hors dépôt (fiche 0030).

- Avant : **FAILED** — `'0.1534' != '0.152'` : la colonne D&C affichait
  ANSUR.
- Après : **OK**.

### Point 7 — l'épaisseur de l'ondulé double est une `mesure`

J'ai ajouté un motif **précis**, `matieres.carton_ondule_double.epaisseur`
→ `mesure`, placé **avant** le joker `matieres.*.epaisseur`. La
première règle qui correspond l'emporte (`audit_origines.py:151`). Sa
source est l'entrée `carton_ondule_double_epaisseur_2026_09_29` de
`mesures.yaml`.

Vérifié valeur par valeur :

| Chemin | Motif retenu | Origine |
| --- | --- | --- |
| `matieres.carton_ondule_double.epaisseur` | le nouveau motif | **mesure** |
| `matieres.carton_plume_5.epaisseur` | `matieres.*.epaisseur` | catalogue — inchangé |

Audit : `catalogue` passe de 17 à **16** et `mesure` de 46 à **47**. Le
total reste 1 440 et `--strict` sort à 0. `controle_regles` compte
**63 motifs, tous atteints** (62 + 1).

**Relevé en passant, non corrigé (hors lot)** : `audit_origines.py
--json` **plante**, avec `TypeError: Object of type date is not JSON
serializable`. Une valeur de type date (entrée n° 300) casse la sortie
machine documentée dans la docstring. Rien dans le dépôt n'appelle
`--json`, donc rien ne l'avait vu.

### Clôture du lot A — et un écart que le point 3 a créé

| Vérification | Résultat |
| --- | --- |
| `regenerer.py` | **sortie 0** ; 112 fichiers suivis, 63 motifs, 46 fiches, 5 pages |
| audit | **1 440 valeurs**, 688 numériques ; `--strict` sort 0, donc **0 non qualifiée** |
| tests | `python -m unittest discover -s tests` : **4 tests, OK** |
| `git status` | propre (le relevé de la semelle, ré-horodaté par la régénération, a été remis à l'état commité : la semelle est hors lot) |
| **empreinte dépôt = site** | **NON** — dépôt `2f589293ec`, site `dcbda4512c` |

**Les quatre tests, et leur échec observé avant correction :**

| Test | Échec vu |
| --- | --- |
| `tests/test_empreinte.py` | `'a247541818' == 'a247541818' : requirements.txt ignoré` |
| `tests/test_regenerer_index.py` | `0 == 0 : index_fiches a échoué, regenerer a rendu 0` |
| `tests/test_index_fiches.py` | `'0016' not found in '0042-premiere.md — premier amendement.'` |
| `tests/test_ratios_ansur.py` | `'0.1534' != '0.152'` |

#### L'écart d'empreinte

Le site a bien été redéployé : il n'affiche plus `7d61326025`. Mais il
affiche une valeur que le poste ne reproduit pas. **Avant le point 3,
les deux concordaient** (vérifié à 23 h 44 la veille).

Ce qui a été éliminé, par mesure :

- **Les pages servies sont identiques aux pages locales**, à la date du
  pied de page près et aux chemins absolus de `pieces.json` près. Ni
  l'un ni l'autre n'entre dans l'empreinte.
- **Le relevé de la semelle n'est pas la cause dans l'image.** Le pied
  de page du site dit « 2026-09-29 » : l'image est construite en UTC, et
  il y était encore le 29. Le relevé y porte donc la date commitée.
  Localement, en revanche, **il est une cause** : un relevé ré-horodaté
  donne `41a73f1e46`. C'est un défaut distinct, latent depuis toujours.
  Une construction faite un autre jour que le commit du relevé change
  l'empreinte. Ce n'est pas corrigé : la semelle est hors lot.
- Aucun fichier non suivi dans `params/ parts/ scripts/ web/`.

**Ce qui reste, déduit et non observé** : le Dockerfile de l'image
n'est pas celui du dépôt. **La documentation de Coolify dit qu'il
injecte par défaut des lignes `ARG` dans le Dockerfile au moment de la
construction.** Le fichier copié par `COPY Dockerfile .` est donc la
version réécrite, et son empreinte ne peut pas être celle du poste.
Sans Docker dans WSL, je n'ai pas pu construire l'image pour le voir.

**Le point 3 a donc recréé, en voulant l'élargir, le défaut que
`empreinte.py` existait pour empêcher** : un signal qu'on ne peut pas
confronter. Il échoue du bon côté (un écart fait croire le site
périmé, il ne fait pas passer un site périmé pour frais), mais il
échoue.

**Non corrigé : c'est une décision.** Trois voies :

1. **Retirer le Dockerfile de l'empreinte** et garder requirements.txt,
   qui n'est pas réécrit. L'égalité revient ; les modifications de
   l'étage constructeur ne sont plus couvertes. Cela contredit la
   consigne du point 3.
2. **Désactiver l'injection d'`ARG` dans Coolify** (réglage avancé de
   l'application). Aucun code à changer, et le Dockerfile reste couvert.
   Mais c'est un réglage hors du dépôt, que Jeremy seul peut faire, et
   rien dans le dépôt ne dirait qu'il est nécessaire.
3. Hacher le Dockerfile privé des lignes injectées : une règle de
   lecture fragile, qui dépend d'un comportement tiers. **Déconseillé.**

---

## Lot A, fin

### A.8 — Empreinte : option 1, le Dockerfile en sort

Jeremy a retenu l'option 1 : le Dockerfile sort de `FICHIERS`, et
`COPY Dockerfile .` est retiré. Le Dockerfile est revenu à l'identique
de sa version d'avant le point 3 : `git diff cc3f17a^ -- Dockerfile` est
vide. requirements.txt reste haché. Le commentaire d'`empreinte.py` dit
pourquoi le Dockerfile n'y est pas, comme une hypothèse et sans
promesse.

**Test** : `tests/test_empreinte.py` ne porte plus que sur
requirements.txt.

- Avec `FICHIERS = ()` : **FAILED** — `'a247541818' == 'a247541818' :
  requirements.txt ignoré par l'empreinte`.
- Avec requirements.txt remis : **OK**.

Empreinte du dépôt à ce commit : `dcd4401aae`. Le verdict sur
l'hypothèse Coolify est à écrire après déploiement (ci-dessous).

**Après déploiement : dépôt `dcd4401aae` = site `dcd4401aae`**, sur
quatre pages (accueil, `/etat/`, page pièce, page atelier). La valeur a
été relevée à 00 h 35, vingt secondes après que le site affichait encore
`dcbda4512c`.

**L'hypothèse Coolify est CONFIRMÉE par l'expérience.** Le Dockerfile
était la seule entrée hachée qui différait entre l'image et le dépôt :
le retirer rétablit l'égalité, sans rien changer d'autre.
L'explication — Coolify injecte des `ARG` — reste celle de sa
documentation ; l'expérience montre que le fichier diffère, pas
comment.

**Une réserve qui prépare A.9** : cette égalité tient aussi parce que
l'image a été construite avant minuit UTC. Son pied de page dit
« 2026-09-29 », donc le relevé de la semelle y porte la date commitée. Une
construction faite après 02 h 00 (heure de Paris) ré-horodaterait le
relevé, et les empreintes divergeraient de nouveau.

### A.9 — Construction déterministe

**Fichiers engendrés portant une date ou une heure de génération :**

| Fichier | Haché ? | Réécrit à chaque construction ? | Traitement |
| --- | --- | --- | --- |
| `parts/semelle_apprentissage.origines.yaml` — « Généré le » | **oui** | **oui** | **corrigé** : la date est retirée, Git la connaît |
| `params/ckpts.manifest.yaml` — « Relevé le » | **oui** | non (`ckpts_backup.py manifest`, à la main) | **corrigé** : la ligne est retirée du générateur et le manifeste régénéré. Diff : cette ligne seule, et `verify` rend 10 conformes |
| `params/upstream_joints.generated.yaml` — « Extrait le » | **oui** | non (`import_upstream_limits.py`, à la main) | **NON corrigé — arrêt** : la fiche 0006 §2 **exige** « la date d'extraction » en tête. La retirer contredirait une fiche appliquée et demanderait une fiche d'amendement, exclue du lot. Le fichier n'est pas réécrit par la construction : il ne casse pas le déterminisme, mais il reste une date dans l'empreinte. `--check` ignore déjà cette ligne. **Décision à prendre.** |
| plan A4 PDF — « Genere le … COMMIT » | non (`exports/`) | oui | laissé : hors empreinte |
| pages du site — pied de page daté | non (`site/`) | oui | laissé : hors empreinte |
| nom de l'archive des poids | non (`exports/`) | — | laissé |

**Test** : `tests/test_construction_deterministe.py` lance `regenerer.py`
en entier, deux fois, sous deux fausses dates système (`datetime.date`
remplacée, 2027-01-01 puis 2027-06-15). Il compare les empreintes et
remet les relevés à leur état initial dans tous les cas.

- Avant la correction : **FAILED** — `'882062005b' != '725f58966d'`.
- Après : **OK** (49 s).

L'empreinte change encore (`2b14b9eede`), comme attendu : le relevé, le
manifeste et deux scripts ont changé.

### Clôture du lot A, fin

| Vérification | Résultat |
| --- | --- |
| `git status` | propre, **même après régénération** : le relevé ne bouge plus |
| `regenerer.py` | sortie 0 |
| empreinte dépôt = site | **`2b14b9eede` = `2b14b9eede`** (accueil, `/etat/`, page pièce ; 00 h 41) |
| tests | **5, OK** (60 s) |

Reste ouvert : la date d'extraction d'`upstream_joints.generated.yaml`,
exigée par la fiche 0006 §2.

---

## Clôture de la caractérisation carton

Décision de Jeremy : le carton a rempli son rôle, qui était de valider la
chaîne. On arrête de le caractériser : ses valeurs ne se transfèrent pas
au robot réel, qui sera fait de pièces imprimées, usinées ou découpées en
métal. Il reste utilisable comme maquette rapide, sans métrologie.
Aucune fiche n'est créée, aucun contrôle n'est ajouté.

### 1 — Fiche 0042 close

Motif : la question du rayon est propre à chaque procédé. Elle sera
reposée avec le procédé réel (rayon d'outil en usinage, machine de l'opérateur CN
en découpe métal). Rien n'est tranché pour le carton.

**Comment « close » est écrit dans l'en-tête.** `close` est une
**espèce** dans `index_fiches.py`, pas un état. La fiche porte donc
`Espèce : close` et `État : archivée`. `archivée` est l'état de la liste
qui dit « fermée, conservée pour mémoire », sans laisser croire que la
question est abandonnée ni tranchée. La taxonomie n'est pas modifiée.

La 0015 garde son renvoi « Amendée par 0042 » : le constat demeure vrai.

### 2 — Fiche 0044 close, sans variante

`Espèce : close`, `État : appliquée`. Seule la voie D est appliquée,
c'est-à-dire la mention sur la page ; aucune variante n'est générée.

**La forme est celle que la question 1 de la 0044 envisageait** : un
champ `exemplaire_coupe:` dans le relevé. Il est écrit par la pièce
pour P2 × `cutter_cartonplume_5` seulement, puisque le contour n'est
identique que pour ce plan. `page_piece` l'affiche en encadré sous la
ligne des caractéristiques. **Le texte vient du relevé, pas du gabarit**
(fiche 0018 : le générateur ne crée aucune donnée). Vérifié dans
`site/piece/semelle_apprentissage/index.html` :

> L'exemplaire réel a été coupé en carton ondulé double de 3,5 mm à
> partir de ce plan en carton plume : le contour 2D est identique, seule
> l'épaisseur diffère.

La géométrie n'a pas changé : les 8 contrôles de la pièce passent, et le
contour, les cotes et le volume sont identiques. Seuls le relevé (4
lignes) et la page changent. Je n'ai pas de navigateur pour regarder la
page rendue : la phrase est vérifiée dans le HTML, pas à l'écran.

### 3 — Registre des mesures

Une phrase en tête de `params/mesures.yaml`, en commentaire : « CARTON :
caractérisation arrêtée le 2026-09-30 — les mesures carton ci-dessous
sont des valeurs d'apprentissage, conservées telles quelles. » Rien n'est
effacé ni modifié : le diff ne comporte que trois lignes ajoutées, et
l'audit strict sort toujours à 0.

### Clôture

| Vérification | Résultat |
| --- | --- |
| `git status` | propre |
| `regenerer.py` | sortie 0 |
| empreinte dépôt = site | **`3438e5db96` = `3438e5db96`** (accueil, `/etat/`, page pièce ; 13 h 29) |
| phrase visible en ligne | oui, présente sur `yxor.fr/piece/semelle_apprentissage/` |
| tests | **5, OK** |

---

## Exigences d'actionnement P2 — premier chiffrage

Rendu : `docs/exigences-actionnement-P2.md`. Lecture et calcul
seulement : aucune pièce, aucun paramètre modifié.

**Deux écarts avec la demande, trouvés en chemin :**

1. **Les données extraites ne portent ni modèle de moteur, ni limite de
   couple ou de vitesse.** Je les ai lues dans les données amont
   épinglées. Le MJCF donne la classe de chaque articulation, qui est le
   modèle Dynamixel, mais seulement un `ctrlrange="-10 10"` commun aux 30
   moteurs, et aucune vitesse. `default.yml` donne `tau_max`,
   `q_dot_max` et `tau_brake_max` par modèle. Les deux sources
   concordent pour les 30 moteurs.
2. **La série de 749 pas est un balancement** (`enveloppes_actionneurs.py`),
   pas une marche. **La série de marche n'était plus conservée : je
   l'avais écrasée** pendant l'audit de la nuit (essai d'une seconde).
   La marche a été relancée : 15 s, 751 pas, 0,106 m/s, pas de chute.
   Couples et vitesses sont dans `exports/actionneurs/marche_15s.csv`.

**Le constat qui compte** : la simulation amont borne le couple par une
courbe couple-vitesse (`motor_control.py`). **Neuf actionneurs de jambe
sur douze touchent leur borne** pendant la marche, jusqu'à 17 % du temps
pour le roulis de hanche gauche. Leurs pointes, et une partie de leurs
RMS, sont donc des **bornes basses**. Les vitesses restent sous 57 % de
leur limite : c'est le couple qui contraint.

**P2** : couple × 6,671, vitesse angulaire × 0,7888, puissance × 5,262.
Les hypothèses (similitude, même densité, allure de Froude) et ce
qu'elles négligent sont écrites. La plus fragile est une masse qui ne
suivra pas s³. Le facteur 1,5 est présenté comme un choix de Jeremy,
pas une norme.

**Non versionné, et signalé** : l'enregistreur et l'analyseur sont dans
`exports/actionneurs/`, ignoré par Git. Les chiffres ne se régénèrent pas
depuis le dépôt seul ; les versionner est une décision.

Clôture : `git status` propre, `regenerer.py` sortie 0, empreinte
dépôt = site = `3438e5db96`. Elle est inchangée, ce qui est attendu :
`docs/` et `journal/` n'entrent pas dans l'empreinte. 5 tests OK.

---

## Dimensionnement par classe d'actionneur

Constat de Jeremy : P1, P2 et P3 fixaient la taille en entrée. Or les
actionneurs se vendent par classes discrètes, et le couple requis croît
en H⁴ : c'est la classe qui doit fixer la taille maximale. Le calcul est
inversé. Aucune pièce, aucun palier modifié, aucune fiche.

### 1 — Enregistreur et analyseur versionnés

**Un écart avec la consigne, par règle** : l'enregistreur n'est **pas**
dans `scripts/`. Il importe `toddlerbot` et doit tourner avec le venv
amont, alors que CLAUDE.md (fiche 0004) réserve ce venv au seul
répertoire `sim/upstream/`.

- `sim/upstream/enregistrer_marche.py` (venv amont) : même boucle que
  `replay_policy.py`, sans vidéo, qui enregistre les couples **et** les
  vitesses. Le garde-fou refuse bien Python 3.14.
- `scripts/analyser_marche.py` (venv projet) : pointe, RMS, vitesse,
  puissance et écrêtage par actionneur. Il lit les modèles de moteur
  dans `default.yml` et le MJCF amont, comme données. Il sort en erreur
  si modèle et classe MJCF divergent.

**Régénération vérifiée** : la série produite par le script versionné a
**le même sha256** que celle de ce matin (`3de8ca2050a16667…`). La
simulation est déterministe. L'analyse redonne les mêmes chiffres, et
30 modèles sur 30 concordent. La série reste dans `exports/` ; les
copies temporaires des scripts y sont supprimées.

### 2 à 5 — Catalogue, dimensionnement inverse, contrôle de cohérence, budget

Rendu : `docs/dimensionnement-par-actionneur.md`. Régénérer :
`.venv/bin/python scripts/dimensionnement.py --markdown`.

**Catalogue** (`params/actionneurs.yaml`) : 7 candidats, chaque valeur
avec sa source et sa date. RobStride est lu dans le PDF constructeur du
2026-09-17 (dépôt GitHub RobStride), extrait avec pypdf ; robstride.com
est illisible en lecture automatique. Valeurs `null`, parce qu'inconnues
ou vues seulement dans un résumé de recherche :

- prix du STS3250 ;
- couple continu et vitesse de l'EduLite 05 ;
- prix de l'adaptateur CAN.

**RS02** : 6 N·m retenu sur consigne de Jeremy. **Le PDF du 2026-09-17
dit encore 7**, et le « 6 nouveau / 5 ancien » de ce PDF concerne le
RS00. Les deux valeurs sont portées. L'écart sur le résultat est de
9 mm.

**Modèle** : masse(H) = S0·(H/H0)³ + 12 actionneurs réels, et un couple
∝ masse × H. Les Dynamixel sont comptés **par axe** : un 2XC430 porte le
roulis ET le tangage de hanche. **L'itération naïve sur la masse
diverge** (dérivée −3) ; elle est résolue par dichotomie à 0,1 mm, la
masse étant recalculée à chaque H.

**Contrôle de cohérence** (marge 1) : ToddlerBot est retrouvé à 0,560 m,
Zeroth-01 à 0,672 m ≥ 0,48. Réserves écrites dans le rapport :

- ToddlerBot est presque tautologique (simulé avec ces bornes) ;
- pour Zeroth-01, **0,48 m n'est dans aucune source** (~0,40 m lu
  deux fois), il a 5 DDL par jambe, et sa marche réelle n'a pas été vue.

Test `tests/test_dimensionnement_coherence.py` : contrôle neutralisé,
**2 échecs vus** (« un Zeroth-01 de 3 m en STS3250 est passé : [] »,
« un STS3250 de 0,1 N·m a porté Zeroth-01 : [] ») ; rétabli, **OK**.

**Résultats (marge 1,5)** :

- homogène : RS03 1,07 m, RS06 0,91 m, AK70-10 0,82 m, RS02 0,79 m ;
  les classes légères restent sous 0,60 m ;
- le roulis de hanche limite tout, et il était écrêté en P1 : **tous
  les résultats sont des plafonds optimistes** ;
- **le découpage mixte demandé est souvent contre-productif** : il met
  la classe légère sur le lacet de hanche, qui devient limitant
  (mixte RS03 / STS3250 : 0,48 m).

**Budget** (`params/budget.yaml`) : TVA 8,1 %, imprévus 15 %
(provisoire, à fixer), taux BCE du jour. La structure est `null` en
attendant l'opérateur CN : **aucun total n'est complet**, tous s'affichent « ≥ ».
Les prix RobStride sont des prix constructeur en CNY, hors import. La
batterie 6S ne correspond pas aux 48 V des caractéristiques.

**Audit** : 1 824 valeurs, dont 1 ambiguë (la hauteur de Zeroth-01), 0
non qualifiée. 101 motifs, tous atteints : deux blocs précis ajoutés à
`origines.yaml`, sans fourre-tout.

Clôture : `git status` propre, `regenerer.py` sortie 0, empreinte
dépôt = site = `761091f4e8` (17 h 33, trois pages). **8 tests, OK.**

---

## Intégration du cadrage

`docs/cadrage.md` a été rédigé hors dépôt, à partir de conversations que
cette session n'a pas eues. Son raisonnement n'est **pas** réécrit. Il
est commité **tel que reçu** (`ea05593`, sha256 `af0c52a479e63aac…`),
puis les corrections sont faites dans un commit séparé, pour que le
diff les montre une à une.

### Chiffres vérifiés (§ 3, 5, 7, et ceux qui en dépendent)

Sources : `docs/dimensionnement-par-actionneur.md`,
`docs/exigences-actionnement-P2.md`, et `scripts/dimensionnement.py`
relancé.

**Conformes** :

- § 3 : ToddlerBot 0,56 m et 3,454 kg ; 15 s, 751 pas, 0,106 m/s, sans
  chute ; 9 actionneurs de jambe sur 12 écrêtés, jusqu'à 17 % pour le
  roulis de hanche ; les réserves sur Zeroth-01.
- § 5 : tailles et masses des 7 classes, écart de 9 mm pour le RS02,
  mixte RS03 / STS3250 à 0,48 m contre 0,60 m, P2 atteint par RS06 et
  RS03 seulement.
- § 7 : les quatre montants, et le défaut de la batterie 22,2 V.

**Corrigés** (4) :

| § | Écrit | Corrigé en | Source |
| --- | --- | --- | --- |
| 2.2 | « 12 actionneurs de jambe … de l'ordre de 1 700 CHF » | « les jambes (12 actionneurs et l'électronique connue, TVA et imprévus compris) … au moins 1 720 CHF » | budget jambes_v1 RS02 = 1 720 CHF TTC. **12 RS02 seuls = 1 044 CHF HT.** Le chiffre attribuait aux actionneurs le total de la phase. |
| 4 | « ≈ marge^−¼ ; RS02 0,87 / 0,79 / 0,73 m » (« pas un calcul du script ») | « ≈ marge^−⅓ ; 0,90 / 0,79 / 0,71 m » (calculé par le script) | `dimensionnement.py`, RS02 homogène, marges 1,0 / 1,5 / 2,0 → 0,902 / 0,789 / 0,711 m. Le rapport 0,902 / 0,789 = 1,143 correspond à 1,5^⅓ (1,145), pas à 1,5^¼ (1,107). |
| 5 | RS03 continu « 21 » | « 20 (21 à la p. 19 du PDF) » | `params/actionneurs.yaml` : 20 retenu, contradiction interne au PDF RobStride |
| 7.2 | RS02 « ≥ 1 947 CHF **avec** le haut du corps v2 » | « puis ≥ 1 947 CHF **de plus** pour le haut du corps v2 » (idem RS03) | 1 947 est le coût de la **seule** phase v2 ; le cumul serait ≥ 3 667 CHF |

**Signalés, non corrigés** (pas une valeur fausse vérifiable, ou une
intention que je ne connais pas) :

- **§ 7.2 : le banc « 2 actionneurs et un adaptateur CAN »** ;
  `params/budget.yaml` chiffre **1** actionneur, un adaptateur **et une
  alimentation de laboratoire**. Le § 6 dit « 1 à 2 ». Il faut aligner
  l'un sur l'autre, et c'est à Jeremy de dire lequel fait foi.
- **§ 6 : « STS3250 … réducteur 1:345 »**. Le catalogue porte `null` :
  ce rapport n'est donné que par un tiers, et la page Feetech ne le
  donne pas. Même remarque pour le jeu « mesuré indépendamment », dont
  la source n'est pas dans le dépôt.
- **§ 5 et § 13.3 : « la configuration avec le lacet de hanche en classe
  lourde est en cours de calcul »**. Aucun calcul n'est en cours dans ce
  dépôt : c'est une piste, pas un résultat.
- **§ 7.1 : taxes françaises, franchise douanière suisse, 90 % du coût
  de ToddlerBot, CPU Intel N95** : ces valeurs ne viennent pas du
  dépôt, je ne les ai pas revérifiées. Le 90 % concorde avec la
  recherche du jour (arXiv 2502.00893v1).
- **CLAUDE.md dit encore « procédé unique : la découpe 2D »**, ce que la
  fabrication séquencée contredit. Je n'y ai pas touché : c'est la
  question ouverte 9 (fiches 0014 et 0015).

Renvois vérifiés : tous les fichiers cités existent. Les fiches 0006,
0042, 0044, 0014 et 0015 disent bien ce que le cadrage leur attribue.

### Fiches des arbitrages décidés

Quatre fiches, une par arbitrage **décidé** du registre (§ 12) qui n'en
avait pas encore. Chacune renvoie à la section du cadrage qui porte le
raisonnement, sans le recopier.

| Fiche | Arbitrage | Espèce · état | Renvoi |
| --- | --- | --- | --- |
| 0047 | démarche inversée | gouvernante · appliquée | cadrage § 2.1, § 3 |
| 0048 | tailles Banc/S/M/L/XL, premier robot S | gouvernante · acceptée | cadrage § 6 |
| 0049 | scripts de chiffrage versionnés | close · appliquée | cadrage § 12 |
| 0050 | fabrication séquencée | gouvernante · acceptée | cadrage § 1, § 12 |

**Pas de fiche** pour ce qui est **proposé** (la marge, la vision,
acheter ou concevoir) : ces points attendent Jeremy.

0047 et 0049 disent qu'elles sont écrites **après** l'application
(règle 5). 0048 et 0050 disent ce qu'elles **ne** font **pas** :
`anthropometry.yaml`, les fiches 0014 et 0015 et la section fabrication
de CLAUDE.md sont inchangés (questions ouvertes 8 et 9). **La 0050
contredit la 0014 et la 0015, et le dit.**

### README

Un encadré sous le titre, et la première ligne de la section Documents,
renvoient à `docs/cadrage.md` comme **le** document à lire en premier.
Le tableau des paliers P1/P2/P3 du README n'est pas touché : son
remplacement est la question ouverte 8.

Clôture : `git status` propre, `regenerer.py` sortie 0, 50 fiches
indexées, 8 tests OK. Empreinte dépôt = site = `761091f4e8`, inchangée
(`docs/`, `decisions/`, `journal/` et le README n'y entrent pas).
`anthropometry.yaml`, 0014 et 0015 : aucun diff.

---

## Mise à jour du cadrage après les décisions du 30-09

**Le texte de l'étude fournisseurs ChatGPT n'était pas joint** : la
consigne ne contenait que l'emplacement « [colle ici le texte de
l'étude ChatGPT] », et aucun fichier correspondant n'existe sur la
machine. Le point B est donc **partiel** (voir B).

### A — Deux décisions enregistrées

- **Marge 1,5 : décidée**, à revoir après le banc. Fiche **0051**,
  cadrage § 4 (titre et règle), § 12 et question 1. Les commentaires de
  `params/actionneurs.yaml`, `origines.yaml` et `dimensionnement.py`
  disaient « à valider » ; ils disent « décidé, fiche 0051 ».
- **Actionneur maison : décidé** selon les modalités du § 8 (piste
  parallèle, interface commune, taille S d'abord, jamais sur le chemin
  critique). Fiche **0052**, cadrage § 8 (titre) et § 12. **« Pour la v1,
  on achète » reste proposé**, et la fiche le dit.
- **Correction de la version 1** : le calcul mixte « lacet de hanche
  lourd » n'était **pas** en cours. Corrigé au § 5 et à la question 3,
  avec une mention datée.

### B — Étude fournisseurs : partiel

**Fait** : la section « Interfaces d'actionneur » (*proposé*) est
ajoutée au cadrage en **§ 8 bis**, pour ne pas renuméroter les § 9 à 14,
auxquels la fiche 0048 renvoie. Elle couvre trois points :

1. une interface d'articulation mécanique YXOR, plus un adaptateur par
   modèle ;
2. `joint.command(position, vitesse, couple)`, avec un backend par
   fabricant et un backend MuJoCo ;
3. une version de fiche et un sha256 par actionneur.

**Non fait, faute du texte** :
`docs/sources/etude-fournisseurs-chatgpt-2026-09-30.md` et la synthèse
du § 9. Le § 9 **reste « ouvert »** dans le cadrage. Écrire la synthèse
sans le fichier aurait créé un renvoi vers un document absent, et
avancé comme « étude » des conclusions que je n'ai pas lues.
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

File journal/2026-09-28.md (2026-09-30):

# Journal — 2026-09-28

Reprise après une semaine. L'état des lieux a montré que le code qui fait
marcher le robot ne vivait que dans un répertoire temporaire de session.
C'était le risque le plus concret du projet : le raisonnement était
consigné, le code exécutable ne l'était pas.

## Tâche 1 — Rapatriement des correctifs

Décision préalable : `decisions/0004-code-amont-dans-le-depot.md`, écrite
**avant** toute modification, conformément à la règle 5.

### Le conflit à résoudre

Ce code importe `toddlerbot`, donc exige Python 3.12 et MuJoCo 3.3.4. Il
ne peut pas tourner avec `~/yxor/.venv`. Or `CLAUDE.md` interdisait
jusqu'ici de lancer du code du dépôt avec le venv amont.

La règle visait un risque précis : **mesurer avec la mauvaise version de
MuJoCo sans s'en apercevoir**. Elle a donc été remplacée par quelque
chose qui traite ce risque au lieu de l'énoncer.

### Ce qui a été créé

| Fichier | Rôle |
| --- | --- |
| `sim/upstream/toddlerbot_fixes.py` | les deux correctifs + le garde-fou |
| `sim/upstream/replay_policy.py` | rejoue une politique, écrit une vidéo |

`sim/upstream/` est le **seul** répertoire du dépôt qui s'exécute avec le
venv amont. Le nom le dit, la fiche 0004 le trace, et `CLAUDE.md` a été
amendé en conséquence.
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

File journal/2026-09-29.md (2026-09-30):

---

# 2026-09-29 — Quatre défauts vus sur un écran, et la limite de la règle 6

Tous les quatre relevés par Jeremy sur yxor.fr, sur mobile. Aucun
n'était visible depuis cette machine.

## 1 — Le site inversait la distinction qu'il existe pour tenir

Le tableau Fabrication affichait :

| Anisotrope | non |
| --- | --- |
| **Cannelures** | **non déterminé**, en rouge |
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

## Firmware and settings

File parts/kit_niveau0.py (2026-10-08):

#!/usr/bin/env python3
"""YXOR Kit, niveau 0 : toutes les pièces du robot en carton, planches A4 à reporter, notice de montage.

    .venv/bin/python parts/kit_niveau0.py              # pièces, contrôles, planches A4, STEP, notice
    .venv/bin/python parts/kit_niveau0.py --rendu      # + image de contrôle (MuJoCo, hors écran)

Créé le 2026-10-08 (prompt « YXOR Kit : décisions et plans du niveau 0 »). DÉCIDÉ
(fiche 0075, Jeremy) : assemblage B — tenons et mortaises, colle non porteuse
seulement, pivots par vis traversante. Matière dessinée : carton ondulé double,
3,5 mm (valeur mesurée ; consigne du prompt, pas un choix écrit par Jeremy).
Toutes les hypothèses de dessin sont dans params/kit.yaml (niveau0), PROPOSÉES.

═══════════════════════════════════════════════════════════════════════
 CE QUE LE CODE DESSINE
═══════════════════════════════════════════════════════════════════════

Chaque segment est un CAISSON, une boîte en plaques planes :
  · deux FLANCS (les plaques les plus larges, extérieures) ;
  · deux FACES, en retrait d'une épaisseur, dont les TENONS (languettes)
    traversent des MORTAISES (fentes) des flancs ;
  · des COUVERCLES (posés sur un bout, débordants) ou des CLOISONS
    (intérieures), tenonnés dans les flancs et les faces.

Une articulation est de deux sortes :
  · CHAPE : les flancs de l'enfant se prolongent en OREILLES qui encadrent le
    parent ; un pivot de chaque côté, sur le même axe ;
  · PLATEAU : l'enfant est vissé par un couvercle sur la sortie du servo du
    parent (lacets, épaule en tangage).

LOGEMENT DE SERVO (STS3215, hardware.yaml, servos) : une FENÊTRE dans la paroi
du parent, à l'aplomb de l'axe décalé de `decalage_sortie`, et une PLAQUE À
FENÊTRE intérieure à mi-hauteur du servo. Au niveau 0, la fenêtre est fermée
par un BOUCHON (pièce à sa taille, percée sur l'axe) et une PLAQUE DE SERRAGE
intérieure : la vis du pivot les serre. Au niveau 1, on retire bouchon et
plaque, on glisse le servo : rien n'est redécoupé.

Un axe passe par la sortie du servo ; les longueurs entre axes successifs sont
celles du Lab (ratios ANSUR × H du Lab, kit.yaml). Ce qui ne tient pas dans ces
longueurs (empilement des axes de hanche, hauteur de cheville, bassin) est
compté comme ÉCART et rapporté : la hauteur totale du Kit est une SORTIE.

Aucun angle rentrant vif (os de chien, dégagements tangents) ; contrôles :
une pièce d'un seul tenant, rayons rentrants, trous ; et, en 3D, aucune
interpénétration entre plaques (un tenon sans mortaise se verrait), ni entre
les servos du niveau 1 posés dans leurs logements et la structure.
"""
from __future__ import annotations

import argparse
import math
import sys
from pathlib import Path

import build123d as bd
import yaml

REPO = Path(__file__).resolve().parents[1]
sys.path.insert(0, str(REPO / "scripts"))
import procedes as PROC  # noqa: E402
from plan_decoupe import ZONE_PLANCHE, ecrire_planches_a4, polylignes_depuis_face  # noqa: E402

NOM = "kit_niveau0"
SORTIE = REPO / "exports" / "parts"
RENDU = REPO / "exports" / NOM
NOTICE = REPO / "docs" / "kit-montage-niveau0.md"
ECART_PLAN = 4.0          # non-cote: espace entre deux pièces sur une planche A4
DELTA = 0.05              # non-cote: mm ; sondage autour d'un sommet
VOL_MIN = 1.0             # non-cote: mm³ ; une intersection plus petite est un artefact numérique
FLECHE = 14.0             # non-cote: longueur de la flèche des cannelures sur le gabarit
X, Y, Z = (1.0, 0.0, 0.0), (0.0, 1.0, 0.0), (0.0, 0.0, 1.0)


def lire(nom: str) -> dict:
    return yaml.safe_load((REPO / "params" / nom).read_text(encoding="utf-8"))


def vneg(a):
    return tuple(-x for x in a)


def vcross(a, b):
    return (a[1] * b[2] - a[2] * b[1], a[2] * b[0] - a[0] * b[2], a[0] * b[1] - a[1] * b[0])


def vadd(*vs):
    return tuple(sum(c) for c in zip(*vs))


def vmul(k, a):
    return tuple(k * x for x in a)


# ─────────────────────────────────────────────────────── données
def donnees() -> dict:
    """Toutes les entrées, lues dans params/ : aucune cote structurelle écrite ici (règle 1)."""
    kit = lire("kit.yaml")
    n0 = kit["niveau0"]
    hw = PROC.charger()
    reg = PROC.reglage(n0["reglage"], hw)
    e = reg["epaisseur"]
    r = PROC.rayon_interieur_min(e, reg.get("rayon_interieur_min_machine"))
    an = lire("anthropometry.yaml")
    R = {k: v["valeur"] for k, v in an["ratios"].items()}
    H = kit["kit_taille"]["H_m"] * 1000.0
    sv = hw["servos"][n0["servo"]]
    vis = hw["vis"][n0["vis_pivot"]]
    j = n0["jeu_fenetre"]
    vo = n0["voile_facteur"] * e
    g = dict(kit=kit, n0=n0, reg=reg, e=e, r=r, d_min=reg.get("trou_decoupe_min") or 2 * r, R=R, H=H,
             L={k: R[k] * H for k in R}, rallonge=(kit["kit_taille"]["hauteur_reelle_m"] - kit["kit_taille"]["H_m"]) * 1000.0,
             sv=sv, vis=vis, d=vis["passage"], j=j, vo=vo, tl=n0["tenon_longueur"], jm=n0["jeu_mortaise"],
             pas=n0["pas_tenons"], Aw=sv["A"] + j, Bw=sv["B"] + j, dec=sv["decalage_sortie"],
             pile=n0["cales_palonnier"] * e, jp=n0["jeu_pivot"], d_in=n0["profondeur_plaque_logement"] * sv["C"],
             ov=vo, rec=n0["recouvrement_plaque"], theta=math.radians(15.0), sigma=reg["masse_surfacique"])
    # servo enfoncé dans la paroi : face supérieure au ras de la face extérieure
    g["prof_servo"] = sv["C"] + sv["bossage_arriere"]
    g["int_servo"] = g["prof_servo"] - e + j            # profondeur intérieure qu'il occupe, jeu compris
    return g


# ─────────────────────────────────────────────────────── primitives 2D
def rect(x0, x1, y0, y1):
    return bd.Pos((x0 + x1) / 2, (y0 + y1) / 2) * bd.Rectangle(abs(x1 - x0), abs(y1 - y0))


def disque(cx, cy, r):
    return bd.Pos(cx, cy) * bd.Circle(r)


class Esquisse:
    """Une plaque en construction : ajouts, retraits, trous. Coordonnées (a, b) de la plaque."""

    def __init__(self, base):
        self.plus, self.moins, self.trous = [base], [], []

    def ajouter(self, s):
        self.plus.append(s)

    def retirer(self, s):
        self.moins.append(s)

    def face(self):
        f = self.plus[0]
        for s in self.plus[1:]:
            f = f + s
        for s in self.moins:
            f = f - s
        for a, b, d in self.trous:
            f = f - disque(a, b, d / 2)
        return f


def centres_tenons(a0, a1, g) -> list[float]:
    """Centres des tenons le long d'un bord [a0, a1] : un voile à chaque bout, au plus `pas` entre deux."""
    utile = (a1 - a0) - 2 * g["vo"] - g["tl"]
    if utile < 0:
        return [] if (a1 - a0) < g["tl"] + 2 * g["r"] + 2 else [(a0 + a1) / 2]
    n = 1 + int(utile // g["pas"])
    if n == 1:
        return [(a0 + a1) / 2]
    p0, p1 = a0 + g["vo"] + g["tl"] / 2, a1 - g["vo"] - g["tl"] / 2
    return [p0 + (p1 - p0) * i / (n - 1) for i in range(n)]


def tenon(es: Esquisse, axe: str, c: float, bord: float, sens: int, g):
    """Un tenon centré en c sur le bord `bord` (le long de a si axe='a'), dépassant de e dans le sens `sens`,
    avec deux dégagements tangents (aucun angle rentrant vif à sa racine)."""
    e, tl, r = g["e"], g["tl"], g["r"]
    if axe == "a":
        es.ajouter(rect(c - tl / 2, c + tl / 2, bord, bord + sens * e))
        for s in (-1, 1):
            es.retirer(disque(c + s * (tl / 2 + r), bord, r))
    else:
        es.ajouter(rect(bord, bord + sens * e, c - tl / 2, c + tl / 2))
        for s in (-1, 1):
            es.retirer(disque(bord, c + s * (tl / 2 + r), r))


def mortaise(es: Esquisse, axe: str, c: float, b0: float, g):
    """Une mortaise de longueur tl + jm (le long de a si axe='a'), de largeur e à partir de b0, os de chien."""
    e, L, r = g["e"], g["tl"] + g["jm"], g["r"]
    if axe == "a":
        x0, x1, y0, y1 = c - L / 2, c + L / 2, b0, b0 + e
    else:
        x0, x1, y0, y1 = b0, b0 + e, c - L / 2, c + L / 2
    es.retirer(rect(x0, x1, y0, y1))
    for x in (x0, x1):
        for y in (y0, y1):
            es.retirer(disque(x, y, r))


def fenetre(es: Esquisse, ca, cb, la, lb, g):
    """Une fenêtre rectangulaire centrée (ca, cb), de côtés la × lb, os de chien aux quatre coins."""
    x0, x1, y0, y1 = ca - la / 2, ca + la / 2, cb - lb / 2, cb + lb / 2
    es.retirer(rect(x0, x1, y0, y1))
    for x in (x0, x1):
        for y in (y0, y1):
            es.retirer(disque(x, y, g["r"]))


# ─────────────────────────────────────────────────────── plaques et caissons
class Plaque:
    """Une pièce plane : sa face 2D (a, b), ses poses 3D (origine, ex, ey, lo), le sens des cannelures."""

    def __init__(self, nom, corps, role, esq, poses, cannelures="a"):
        self.nom, self.corps, self.role, self.esq, self.poses = nom, corps, role, esq, poses
        self.cannelures = cannelures

    def finir(self, g):
        self.face = self.esq.face()
        fs = self.face.faces()
        if len(fs) != 1:
            raise ValueError(f"{self.nom} : {len(fs)} morceaux au lieu d'une pièce d'un seul tenant")
        self.solide = bd.extrude(self.face, amount=g["e"])
        bb = fs[0].bounding_box()
        self.dims = (bb.size.X, bb.size.Y)
        self.aire = fs[0].area
        return self

    def solides(self):
        out = []
        for O, ex, ey, lo, miroir in self.poses:
            n = vcross(ex, ey)
            pl = bd.Plane(origin=vadd(O, vmul(lo, n)), x_dir=ex, z_dir=n)
            s = self.solide.moved(bd.Location(pl))
            if miroir:
                s = s.mirror(bd.Plane.XZ)
            out.append(s)
        return out




class Caisson:
    """Repère (O, U, V), W = U × V. u ∈ [0, L] ; flancs ⟂ V aux bords v = ±W/2 (les plus larges) ; faces ⟂ W,
    en retrait de e (leur face extérieure à w = ±(Dp/2 − e)), tenonnées dans les flancs ; couvercles posés
    sur un bout (u < 0 ou u > L), débordants ; cloisons intérieures. `cote` : le caisson existe à gauche et,
    en miroir, à droite."""

    def __init__(self, nom, O, U, V, L, W, Dp, g, cote=True):
        self.nom, self.O, self.U, self.V, self.Wd = nom, O, U, V, vcross(U, V)
        self.L, self.W, self.Dp, self.g, self.cote = L, W, Dp, g, cote
        self.couv = {0: False, 1: False}
        self.cloisons = []          # positions u (bas de la plaque)
        self.oreilles = []          # dict(bout, wc, we, long) : prolongements des flancs, trou au bout
        self.logements = []         # dict(paroi, s, sa, sb, sens, vers, axe)
        self.trous = []             # (paroi, s, a, b, d)

    def p(self, u, v, w):
        return vadd(self.O, vmul(u, self.U), vmul(v, self.V), vmul(w, self.Wd))

    # extérieur des parois, dans le repère du caisson
    def paroi_ext(self, paroi):
        e = self.g["e"]
        return {"flanc": self.W / 2, "face": self.Dp / 2 - e}[paroi]

    def logement(self, paroi, s, sa, sb, sens, vers, axe):
        """Un servo dont la sortie est en (sa, sb) dans la paroi ; A le long de `sens` ('a' ou 'b') ; le corps
        du servo du côté `vers` (±1) de la sortie, le long de A."""
        g = self.g
        lg = dict(paroi=paroi, s=s, sa=sa, sb=sb, sens=sens, vers=vers, axe=axe)
        if sens == "a":
            lg["fen"] = (sa + vers * g["dec"], sb, g["Aw"], g["Bw"])
        else:
            lg["fen"] = (sa, sb + vers * g["dec"], g["Bw"], g["Aw"])
        self.logements.append(lg)
        return lg

    def _preparer(self):
        g, e, W, Dp, L = self.g, self.g["e"], self.W, self.Dp, self.L
        vi, bf = W / 2 - e, Dp / 2 - 2 * e
        self._cl = [(u0, [], None) for u0 in self.cloisons]
        self._pf = []        # plaques à fenêtre ⟂ V : (tc, v0) → mortaises dans les faces
        self._pw = []        # plaques à fenêtre ⟂ W : (tc, w0) → mortaises dans les flancs
        couv_fen = {0: [], 1: []}
        for lg in self.logements:
            ca, cb, la, lb = lg["fen"]
            if lg["paroi"] in ("flanc", "face"):
                a0 = max(0.0, ca - la / 2 - g["vo"] - g["tl"])           # la plaque reste dans le caisson
                a1 = min(L, ca + la / 2 + g["vo"] + g["tl"])
                tc = centres_tenons(a0, a1, g)
                if lg["paroi"] == "flanc":
                    v_int = lg["s"] * (W / 2 - e)                 # face intérieure du flanc
                    v0 = v_int - lg["s"] * g["d_in"] - (e if lg["s"] > 0 else 0)
                    lg["pl"] = dict(a0=a0, a1=a1, tc=tc, v0=v0)
                    self._pf.append((tc, v0))
                else:
                    w_int = lg["s"] * bf
                    w0 = w_int - lg["s"] * g["d_in"] - (e if lg["s"] > 0 else 0)
                    lg["pl"] = dict(a0=a0, a1=a1, tc=tc, w0=w0)
                    self._pw.append((tc, w0))
            else:
                couv_fen[lg["s"]].append((ca, cb, la, lb))
        # une seule plaque par couvercle, avec toutes ses fenêtres ; plus étroite (sans tenons dans les flancs)
        # si des plaques de logement de flanc occupent la même hauteur
        for k, fens in couv_fen.items():
            if not fens:
                continue
            u0 = (-e + g["d_in"]) if k == 0 else (L - g["d_in"])
            vlim = None
            for lg in self.logements:
                if lg["paroi"] == "flanc" and lg["pl"]["a0"] - e <= u0 + e and u0 <= lg["pl"]["a1"]:
                    lim = W / 2 - e - g["int_servo"] - g["jp"]            # s'arrête avant le corps du servo
                    vlim = lim if vlim is None else min(vlim, lim)
            self._cl.append((u0, fens, vlim))
        self.tf = centres_tenons(0, L, g)
        self.tcv = centres_tenons(-vi, vi, g)
        self.tcw = centres_tenons(-bf, bf, g)
        self.tfw = centres_tenons(-Dp / 2, Dp / 2, g)

    def _fenetres(self, es, paroi, s):
        for lg in self.logements:
            if lg["paroi"] == paroi and lg["s"] == s:
                fenetre(es, *lg["fen"], self.g)
        for (par, ss, a, b, d) in self.trous:
            if par == paroi and ss == s:
                es.trous.append((a, b, d))

    def _poses(self, ex, ey, lo):
        return [(self.O, ex, ey, lo, False)] + ([(self.O, ex, ey, lo, True)] if self.cote else [])

    def plaques(self) -> list[Plaque]:
        self._preparer()
        g, e, L, W, Dp = self.g, self.g["e"], self.L, self.W, self.Dp
        vi, bf = W / 2 - e, Dp / 2 - 2 * e
        out = []
        # ── flancs ⟂ V : (a, b) = (u, w)
        for s in (1, -1):
            es = Esquisse(rect(0, L, -Dp / 2, Dp / 2))
            for sg in (1, -1):
                for c in self.tf:
                    mortaise(es, "a", c, bf if sg > 0 else -bf - e, g)
            for u0, _, vl in self._cl:
                if vl is None:
                    for c in self.tcw:
                        mortaise(es, "b", c, u0, g)
            for tc, w0 in self._pw:
                for c in tc:
                    mortaise(es, "a", c, w0, g)
            for k in (0, 1):
                if self.couv[k]:
                    for c in self.tfw:
                        tenon(es, "b", c, 0 if k == 0 else L, -1 if k == 0 else 1, g)
            for o in self.oreilles:
                ub = 0 if o["bout"] == 0 else L
                sg = -1 if o["bout"] == 0 else 1
                ua = ub + sg * o["long"]
                es.ajouter(rect(min(ub, ua), max(ub, ua), o["wc"] - o["we"] / 2, o["wc"] + o["we"] / 2))
                es.ajouter(disque(ua, o["wc"], o["we"] / 2))
                es.trous.append((ua, o["wc"], g["d"]))
                for t in (-1, 1):
                    bord = o["wc"] + t * o["we"] / 2
                    if abs(bord) < Dp / 2 - 1e-6:           # racine dans le flanc : dégagement tangent
                        es.retirer(disque(ub, bord + t * g["r"], g["r"]))
            self._fenetres(es, "flanc", s)
            out.append(Plaque(f"{self.nom}.flanc{'+' if s > 0 else '-'}", self.nom, "flanc", es,
                              self._poses(self.U, self.Wd, -W / 2 if s > 0 else W / 2 - e)))
        # ── faces ⟂ W : (a, b) = (u, v)
        for s in (1, -1):
            es = Esquisse(rect(0, L, -vi, vi))
            for c in self.tf:
                for sg in (1, -1):
                    tenon(es, "a", c, sg * vi, sg, g)
            for u0, _, vl in self._cl:
                for c in (self.tcv if vl is None else centres_tenons(-vl, vl, g)):
                    mortaise(es, "b", c, u0, g)
            for tc, v0 in self._pf:
                for c in tc:
                    mortaise(es, "a", c, v0, g)
            for k in (0, 1):
                if self.couv[k]:
                    for c in self.tcv:
                        tenon(es, "b", c, 0 if k == 0 else L, -1 if k == 0 else 1, g)
            self._fenetres(es, "face", s)
            out.append(Plaque(f"{self.nom}.face{'+' if s > 0 else '-'}", self.nom, "face", es,
                              self._poses(self.U, self.V, bf if s > 0 else -bf - e)))
        # ── cloisons, dont les plaques à fenêtre des logements des couvercles ⟂ U : (a, b) = (v, w)
        n = 0
        for u0, fen, vl in self._cl:
            vv = vi if vl is None else vl
            es = Esquisse(rect(-vv, vv, -bf, bf))
            if vl is None:
                for c in self.tcw:
                    for sg in (1, -1):
                        tenon(es, "b", c, sg * vi, sg, g)
            for c in (self.tcv if vl is None else centres_tenons(-vl, vl, g)):
                for sg in (1, -1):
                    tenon(es, "a", c, sg * bf, sg, g)
            for f in fen:
                fenetre(es, *f, g)
            n += 0 if fen else 1
            nom = f"{self.nom}.plaque_logement_{'bas' if u0 < L / 2 else 'haut'}" if fen else f"{self.nom}.cloison{n}"
            out.append(Plaque(nom, self.nom, "plaque à fenêtre" if fen else "cloison", es,
                              self._poses(self.V, self.Wd, u0), cannelures="a" if W >= Dp else "b"))
        # ── plaques à fenêtre des logements des flancs et des faces
        for lg in self.logements:
            if lg["paroi"] == "couv":
                continue
            pl = lg["pl"]
            ca, cb, la, lb = lg["fen"]
            if lg["paroi"] == "flanc":
                es = Esquisse(rect(pl["a0"], pl["a1"], -bf, bf))
                for c in pl["tc"]:
                    for sg in (1, -1):
                        tenon(es, "a", c, sg * bf, sg, g)
                fenetre(es, ca, cb, la, lb, g)
                # repère (U, Wd) : n = −V ; la plaque occupe v ∈ [v0, v0 + e]
                out.append(Plaque(f"{self.nom}.{lg['axe']}.plaque", self.nom, "plaque à fenêtre", es,
                                  self._poses(self.U, self.Wd, -pl["v0"] - e)))
            elif lg["paroi"] == "face":
                es = Esquisse(rect(pl["a0"], pl["a1"], -vi, vi))
                for c in pl["tc"]:
                    for sg in (1, -1):
                        tenon(es, "a", c, sg * vi, sg, g)
                fenetre(es, ca, cb, la, lb, g)
                out.append(Plaque(f"{self.nom}.{lg['axe']}.plaque", self.nom, "plaque à fenêtre", es,
                                  self._poses(self.U, self.V, pl["w0"])))
        # ── couvercles ⟂ U : (a, b) = (v, w), débordants
        for k in (0, 1):
            if not self.couv[k]:
                continue
            ov = g["ov"]
            es = Esquisse(rect(-W / 2 - ov, W / 2 + ov, -Dp / 2 - ov, Dp / 2 + ov))
            for sg in (1, -1):
                for c in self.tfw:
                    mortaise(es, "b", c, W / 2 - e if sg > 0 else -W / 2, g)
                for c in self.tcv:
                    mortaise(es, "a", c, bf if sg > 0 else -bf - e, g)
            self._fenetres(es, "couv", k)
            out.append(Plaque(f"{self.nom}.couvercle_{'bas' if k == 0 else 'haut'}", self.nom, "couvercle", es,
                              self._poses(self.V, self.Wd, -e if k == 0 else L),
                              cannelures="a" if W >= Dp else "b"))
        # ── niveau 0 : bouchon et plaque de serrage de chaque logement
        for lg in self.logements:
            ca, cb, la, lb = lg["fen"]
            nm = f"{self.nom}.{lg['axe']}"
            b = Esquisse(rect(ca - la / 2, ca + la / 2, cb - lb / 2, cb + lb / 2))
            b.trous.append((lg["sa"], lg["sb"], g["d"]))
            ca_ = "a" if la >= lb else "b"
            out.append(Plaque(f"{nm}.bouchon", self.nom, "bouchon (niveau 0)", b, self._poses_paroi(lg, 0), ca_))
            rc = g["rec"]
            sp = Esquisse(rect(ca - la / 2 - rc, ca + la / 2 + rc, cb - lb / 2 - rc, cb + lb / 2 + rc))
            sp.trous.append((lg["sa"], lg["sb"], g["d"]))
            out.append(Plaque(f"{nm}.serrage", self.nom, "plaque de serrage (niveau 0)", sp,
                              self._poses_paroi(lg, 1), ca_))
        return out

    def _poses_paroi(self, lg, couche):
        """Dans le plan de la paroi du logement (couche 0) ou juste à l'intérieur (couche 1)."""
        e, W, Dp, L = self.g["e"], self.W, self.Dp, self.L
        p, s = lg["paroi"], lg["s"]
        if p == "flanc":                                   # n = −V
            lo = (-W / 2 if s > 0 else W / 2 - e) + couche * (e if s > 0 else -e)
            return self._poses(self.U, self.Wd, lo)
        if p == "face":                                    # n = +W
            bf = Dp / 2 - 2 * e
            lo = (bf if s > 0 else -bf - e) - couche * (e if s > 0 else -e)
            return self._poses(self.U, self.V, lo)
        lo = (-e if s == 0 else L) + couche * (e if s == 0 else -e)   # n = +U
        return self._poses(self.V, self.Wd, lo)
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

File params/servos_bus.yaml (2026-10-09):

# Marché des servos à bus série avec retour de position, AUTRES que Feetech et Dynamixel — VERSÉ le 2026-10-09
#
# Étude d'un agent (question de Jeremy, 2026-10-08 : « Pourquoi choisir du Feetech ? Car ce sont les actionneurs
# les moins chers du marché ? »). Chaque valeur vient d'une source TÉLÉCHARGÉE, inscrite à params/fournisseurs.yaml
# (marche_servo_*, sha256, non redistribuable) ; une valeur non lue est null ; seule conversion : kgf·cm → N·m
# (× 0,0980665). Aucun achat recommandé (fiche 0066).
# ⚠ Boutiques Shopify (hiwonder.com…) lues via le relais r.jina.ai (champ `via` des sources) ; RobotShop et le
#   wiki Lynxmotion bloqués (fiches Lynxmotion : PDF hébergés par DigiKey) ; aucun prix en CHF ; Waveshare =
#   Feetech rebaptisé : PROBABLE (bibliothèque « SCServo »), non établi ; couple continu publié seulement par
#   HerkuleX et Lynxmotion. Feetech et Dynamixel : déjà dans params/actionneurs.yaml.
modeles:
- famille: Hiwonder
  fabricant: Hiwonder (Shenzhen)
  modele: LX-15D
  couple_blocage:
    valeur: 17
    unite_origine: kgf·cm
    tension_V: 7.4
    N_m: 1.667
    conversion: × 0,0980665 (kgf·cm → N·m)
  couple_continu: null
  vitesse_vide:
    s_60deg: 0.22
    tension_V: 7.4
  masse_g: 43
  cotes_mm:
  - 44.02
  - 22.92
  - 35.12
  plage_tension_V:
  - 6
  - 8.4
  bus: UART série (commande série), 115200 bauds ; demi/full duplex non précisé
  protocole_licence:
    documentation_publique: protocole fourni (« Provide bus servo communication protocol », fiche LX-15D) ; Hiwonder
      le dit « our private serial protocol »
    sdk_licence: null
  prix:
    valeur: 16.99
    devise: USD
    tva_incluse: null
    vendeur: hiwonder.com (boutique, region_country=US)
  prix_chf: null
  disponibilite_ch_ue:
    ch: null
    ue: null
    note: stock non lisible (gabarit « In stock / Out of stock » ambigu dans le rendu)
  feetech_rebaptise: null
  notes: '15 kgf·cm à 6 V ; courant de blocage 2,4–3 A. Protocole : licence ouverture via la même fiche.'
  sources:
  - champ: couple_blocage
    source: marche_servo_hw_lx15d
  - champ: vitesse_vide
    source: marche_servo_hw_lx15d
  - champ: masse_g
    source: marche_servo_hw_lx15d
  - champ: cotes_mm
    source: marche_servo_hw_lx15d
  - champ: plage_tension_V
    source: marche_servo_hw_lx15d
  - champ: bus
    source: marche_servo_hw_lx15d
  - champ: prix
    source: marche_servo_hw_lx15d
  - champ: protocole_licence
    source: marche_servo_hw_lx15d
- famille: Hiwonder
  fabricant: Hiwonder (Shenzhen)
  modele: LX-225
  couple_blocage:
    valeur: 25
    unite_origine: kgf·cm
    tension_V: 7.4
    N_m: 2.452
    conversion: × 0,0980665 (kgf·cm → N·m)
  couple_continu: null
  vitesse_vide:
    s_60deg: 0.2
    tension_V: 7.4
  masse_g: 63
  cotes_mm:
  - 40
  - 20.14
  - 51.1
  plage_tension_V:
  - 6
  - 8.4
  bus: UART série (commande série), 115200 bauds ; demi/full duplex non précisé
  protocole_licence:
    documentation_publique: protocole fourni (« Provide bus servo communication protocol », fiche LX-15D) ; Hiwonder
      le dit « our private serial protocol »
    sdk_licence: null
  prix:
    valeur: 17.99
    devise: USD
    tva_incluse: null
    vendeur: hiwonder.com (boutique, region_country=US)
  prix_chf: null
  disponibilite_ch_ue:
    ch: null
    ue: null
    note: stock non lisible (gabarit « In stock / Out of stock » ambigu dans le rendu)
  feetech_rebaptise: null
  notes: courant de blocage 4 A
  sources:
  - champ: couple_blocage
    source: marche_servo_hw_lx225
  - champ: vitesse_vide
    source: marche_servo_hw_lx225
  - champ: masse_g
    source: marche_servo_hw_lx225
  - champ: cotes_mm
    source: marche_servo_hw_lx225
  - champ: plage_tension_V
    source: marche_servo_hw_lx225
  - champ: bus
    source: marche_servo_hw_lx225
  - champ: prix
    source: marche_servo_hw_lx225
  - champ: protocole_licence
    source: marche_servo_hw_lx15d
- famille: Hiwonder
  fabricant: Hiwonder (Shenzhen)
  modele: LX-824HV
  couple_blocage:
    valeur: 17
    unite_origine: kgf·cm
    tension_V: 11.1
    N_m: 1.667
    conversion: × 0,0980665 (kgf·cm → N·m)
  couple_continu: null
  vitesse_vide:
    s_60deg: 0.2
    tension_V: 11.1
  masse_g: 57
  cotes_mm:
  - 40.0
  - 20.14
  - 51.1
  plage_tension_V:
  - 9
  - 12.6
  bus: UART série (commande série), 115200 bauds ; demi/full duplex non précisé
  protocole_licence:
    documentation_publique: protocole fourni (« Provide bus servo communication protocol », fiche LX-15D) ; Hiwonder
      le dit « our private serial protocol »
    sdk_licence: null
  prix:
    valeur: 17.99
    devise: USD
    tva_incluse: null
    vendeur: hiwonder.com (boutique, region_country=US)
  prix_chf: null
  disponibilite_ch_ue:
    ch: null
    ue: null
    note: stock non lisible (gabarit « In stock / Out of stock » ambigu dans le rendu)
  feetech_rebaptise: null
  notes: courant de blocage 1,7–2 A
  sources:
  - champ: couple_blocage
    source: marche_servo_hw_lx824hv
  - champ: vitesse_vide
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

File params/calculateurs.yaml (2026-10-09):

# Marché des calculateurs — lu par scripts/marche_composants.py
#
# DONNÉES SEULEMENT (2026-10-07) : aucune intégration à l'explorateur, aucun achat (fiche 0066).
# Contexte DÉCIDÉ (fiche 0070, Jeremy, 2026-10-07) : « Les deux robots, YXOR Lab et YXOR, fonctionnent
# entièrement sur batterie. Je préfère NVIDIA Jetson, mais je veux une comparaison chiffrée avec le
# Raspberry Pi 5 et ses cartes d'IA. »
#
# Même méthode que le marché des actionneurs : une valeur non lue est null ; deux sources qui divergent,
# la plus prudente (fiche 0064), l'autre en note. Relevé par quatre agents de Claude Code le 2026-10-07 ;
# chaque source est TÉLÉCHARGÉE (hors du dépôt) et inscrite au registre params/fournisseurs.yaml sous
# la clé citée ici (marche_<domaine>_<id>), redistribuable: false. Les valeurs dérivées (énergie non
# publiée, volume, densités, CHF HT, TOPS/W, canaux CAN) sont CALCULÉES par scripts/marche_composants.py,
# jamais déclarées ici.
#
# TOPS : un chiffre « AI Performance » n'est comparable qu'en INT8 DENSE ; voir meta.mises_en_garde_tops.

meta:
  perimetre: C — calculateurs embarqués (Jetson, Raspberry Pi et IA), relevé du 2026-10-07
  conventions:
  - valeur null = non lue dans une source téléchargée ; aucune estimation.
  - 'tva_incluse : false si la source dit HT ; un taux (0.20) quand il se déduit des prix TTC et HT affichés ; true
    si la source dit TTC sans taux ; null si la source ne dit rien (prix MSRP NVIDIA et prix de liste Raspberry
    Pi).'
  - 'Deux sources divergentes : valeur la plus prudente retenue, l''autre en note.'
  - Fichiers sources dans fichiers/ ; empreinte sha256 et taille calculées au moment de la génération.
  mises_en_garde_tops:
  - 'NVIDIA Orin : « AI Performance » = INT8 SPARSE, GPU + DLA additionnés. Le dense vaut la moitié ; GPU seul en
    INT8 dense : Nano 4GB 17, Nano 8GB 33, NX 38, AGX 32GB 54, AGX 64GB 85, Industrial 78.'
  - La page du kit Orin Nano Super écrit « 67 INT8 TOPS » sans le mot sparse ; le fiche J401 de Seeed donne encore
    les TOPS d'avant Super (20/40/70/100).
  - 'NVIDIA Thor (T2000–T5000) : TFLOPS FP4 SPARSE seulement, aucune valeur INT8 publiée sur les pages lues ; «
    7.5x AGX Orin » compare FP4 sparse à INT8 sparse.'
  - 'AI HAT+ 2 (Hailo-10H) : 40 TOPS en INT4 ; vision « comparable » à l''AI HAT+ 26 TOPS.'
  - 'Hailo-8 / 8L (AI HAT+) : précision et parcimonie non publiées par Raspberry Pi.'
  - 'AGX Orin 32GB : la même page NVIDIA donne 241 puis 200 TOPS : 200 retenu.'
  contexte_marche_2026:
  - Hausse NVIDIA de juillet 2026 (jusqu'à +101 %), ex. kit Orin Nano Super 249 $ → 399 $ (nv_faq, cnx_prix).
  - Fin de vie accélérée des Jetson LPDDR4 (TX2 NX, TX2i, AGX Xavier, Xavier NX), dernière livraison 15/07/2027
    (cnx_lpddr4_eol).
  - 'Nouveautés 2026 : T4000 (en vente), T3000 et T2000 annoncés pour T1 2027 ; AI HAT+ 2 (Hailo-10H) ; brief RPi
    5 d''octobre 2026 (16GB à 305 $).'
  - 'Raspberry Pi AI Kit : fin de production.'
  trous:
  - 'Masses des modules Jetson et des kits NVIDIA : non publiées sur les pages lues (fiches techniques derrière
    inscription).'
  - 'Consommation au repos et typique : aucune valeur fabricant pour Jetson ni Raspberry Pi (seulement des plages
    de modes).'
  - 'Hailo-8 M.2 seul et pages hailo.ai : bloquées (403), non relevées.'
  - 'Pages raspberrypi.com, pi-shop.ch, digitec.ch, connecttech.com : protection anti-robot, non téléchargées. Aucun
    prix suisse relevé.'
  - 'ONNX Runtime : non vérifié. Tensions d''entrée des kits NVIDIA : non lues.'
marche:
  sources:
    marche_ver_adafruit_ai_hat_2:
      titre: Adafruit (US) — Raspberry Pi AI HAT+ 2 (6451)
      url: https://www.adafruit.com/product/6451
      editeur: Adafruit
      date: '2026-10-07'
      fichier: adafruit_6451.html
      empreinte: 54804833b0c9fb6dd1dcf1d7c0d73979a26b04d06fd63a13d381baf0b4649491
      octets: 80870
      conditions: page publique, consultée sans compte
      primaire: false
      note: null
    marche_ver_auvidea_jnx120:
      titre: Auvidea — JNX120 carrier board for NVIDIA Jetson Orin Nano/NX
      url: https://auvidea.eu/product/jnx120-carrier-board-for-nvidia-jetson-orin-nano-nx/
      editeur: Auvidea
      date: '2026-10-07'
      fichier: auvidea_jnx120.html
      empreinte: 3c59401b2188a6e0af41dbaff95a7742a8198f034e723f799d1806e0497793a5
      octets: 311956
      conditions: page publique, consultée sans compte
      primaire: true
      note: 'Page : « currently in design, first prototype quantities by January 2026 » ; tableau comparatif : JNX120S
        « samples now ».'
    marche_ver_core_ai_hat_plus_2:
      titre: Core Electronics (AU) — Raspberry Pi AI HAT+ 2 (CE10475)
      url: https://core-electronics.com.au/raspberry-pi-ai-hat-plus-2.html.plain.md
      editeur: Core Electronics
      date: '2026-10-07'
      fichier: core_ai_hat_plus_2.md
      empreinte: 9a0a41592221e154229b4a894b03c783c1236319067563be477fcfb34b0cacfb
      octets: 4732
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

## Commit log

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2026-09-20 Phase 1 étape A : mesures sous WSL2, outils corrigés
    La migration VirtualBox -> WSL2 lève le blocage AVX : mujoco 3.13.0
    démarre, les trois mesures en suspens sont faites.
    Mesures (humanoid.xml) :
    - temps simulé / temps réel sans affichage : x155
    - viewer 1280x720 : 10,7 FPS ; 640x480 : 12,9 FPS
    - ombres coupées : 57 FPS en 1280x720 (x5,3) — la carte d'ombre
    4096x4096 par lumière domine le coût, pas la résolution
    - rendu hors écran EGL : ~1,2 s l'image en 1280x720, image vérifiée
    WSLg ouvre bien une fenêtre mais n'apporte aucun GPU : /dev/dri est
    absent, le rendu reste llvmpipe (logiciel).
    Corrections des deux outils, jamais exécutés jusqu'ici :
    - render.py ne créait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
2026-09-20 Pile ToddlerBot installée et ancrée, environnement bicéphale
    Fiche 0002 écrite avant application (règle 5) : ancrage de l'amont au
    commit e337f3b177b4b53abff70b31d1695a7b66cc6d2e (main, 2026-04-19,
    toddlerbot 0.2.0, MIT), cloné hors du dépôt dans ~/upstream/toddlerbot.
    Environnement désormais bicéphale, acté dans la fiche et dans CLAUDE.md :
    - code YXOR : ~/yxor/.venv Python 3.14.4, MuJoCo 3.13.0
    - pile ToddlerBot: ~/upstream/.../.venv Python 3.12.14, MuJoCo 3.3.4
    Motif : l'amont épingle numpy 1.26.4, jaxlib 0.4.28 et torch 2.3.1, qui
    plafonnent à cp312. Corrige un constat du matin qui portait sur les
    versions courantes (cp314 disponible) au lieu des version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
2026-09-28 Rapatriement des correctifs ToddlerBot dans sim/upstream/
    Le code qui fait marcher le robot ne vivait que dans un répertoire
    temporaire de session : le raisonnement était consigné, l'exécutable non.
    Fiche 0004 écrite avant application (règle 5) : sim/upstream/ est le seul
    répertoire du dépôt qui s'exécute avec le venv amont, parce qu'il importe
    toddlerbot (Python 3.12 / MuJoCo 3.3.4). CLAUDE.md amendé en conséquence.
    La règle des deux interpréteurs passe de déclarative à exécutée :
    require_upstream_env() vérifie Python, MuJoCo et toddlerbot, puis s'arrête
    en nommant l'interpréteur correct. Vérifié dans les deux sens — le venv
    YXOR est refusé (exit 1), le venv amon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
2026-09-28 joints.yaml réconcilié appliqué + structure à 4 identités proposée
    Chantier 2 clos : les 17 butées sont tirées programmatiquement de la
    section `articulations` du fichier généré, aucune saisie manuelle. Ajout
    de `sens` (+1/-1) et d'un bloc `symetrie` justifiant le jeu unique de
    butées. elbow -> elbow_roll avec axe corrigé y -> x, wrist_yaw ->
    elbow_yaw.
    Chantier 3, proposition non appliquée. Le modèle représente les
    transmissions de trois façons distinctes, que le chantier 2 agrégeait
    sous une seule étiquette : couplage polynomial (9 articulations), bielle
    à quatre barres par contraintes de site (neck_pitch), différentiel à
    tendons (waist_yaw, waist_roll), et prise dir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
    [joints.yaml]
2026-09-28 Structure à cinq identités appliquée à joints.yaml + fiche 0007
    joints.yaml passe à 593 lignes. Chaque articulation porte fonction,
    articulation, actionnement, modele et materiel, chacun avec sa source.
    La règle 3 est intacte : `nom` reste l'unique identifiant qui fait foi.
    Validé : YAML correct, 30 DDL, aucun bloc materiel sans version.
    Ajustement 1 — `version` obligatoire dans tout bloc materiel, avec le
    genou en cas d'école dans l'en-tête : « liaison parallèle déportant le
    moteur vers la hanche » était vraie pour ToddlerBot 1.0 et fausse pour
    la 2.0. Sans ce champ, rien ne signalait que l'affirmation avait cessé
    d'être vraie. Version de référence : ToddlerBot 2.0.0 (C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
    [joints.yaml]
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2026-09-28 Traçabilité de l'origine des cotes (fiche 0010 + audit)
    Aucune question juridique n'est tranchée : ce commit produit un
    inventaire, pas un avis.
    Convention posée avant toute pièce : propre / catalogue / amont / mesure,
    plus ambigu (préféré à tout choix par défaut) et non_qualifie (défaut
    signalé par l'audit).
    Règle pour le code build123d : l'origine est portée par l'ACCESSEUR,
    jamais annotée ligne à ligne. Un mot par cote — celui qu'il fallait
    écrire de toute façon pour aller chercher la valeur. L'accesseur refuse
    la mauvaise origine, donc on ne peut pas blanchir une cote amont en la
    demandant comme propre. `mesure` seule exige une déclaration en ligne
    avec instrument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
2026-09-28 Audit des sources : vérification, pas synthèse
    Aucun fichier de params/ modifié. Rien dessiné.
    1 — Ratios. Source primaire Drillis & Contini (1966) NON ACCESSIBLE.
    Plus proche obtenu : chapitre 4 de Winter, exemplaire servi par
    l'université de l'Illinois — secondaire de référence.
    LONGUEURS : attribution correcte (Winter écrit que la figure 4.1 est de
    Drillis & Contini) mais valeurs NON VÉRIFIABLES — elles sont dans un
    graphique, aucun des quatorze nombres n'apparaît dans le texte du PDF.
    Corroboration tierce faible seulement. Deux valeurs sont en outre des
    dérivations et non des ratios publiés : tronc_hauteur = 0,818 - 0,530 et
    cou_hauteur = 1 - 0,130 - 0,818.
    MASSES : v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
2026-09-28 Sources rétablies dans anthropometry.yaml, nature des cotes appliquée
    Fiches 0012 et 0013 écrites avant application.
    1 — anthropometry.yaml corrigé, source au niveau de la LIGNE et non plus
    du fichier. Attribution scindée : longueurs = Drillis & Contini (Winter
    fig. 4.1), masses = Dempster (Winter tab. 4.1, code M). tibia 0.047 ->
    0.0465, pied 0.014 -> 0.0145, main 0.006 ajoutée, tete renommée
    tete_et_cou. tronc_hauteur et cou_hauteur marquées dérivées par
    soustraction, avec le calcul. Mention franche que ces valeurs ont
    d'abord été écrites de mémoire par un modèle de langage le 2026-09-20.
    tete renommée et non retirée : la valeur est juste, c'est son nom qui
    était faux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
2026-09-28 Pas d'imprimante 3D : inventaire complet et architecture en plaques
    Ni params/ ni CLAUDE.md corrigés — la liste complète est soumise, pas un
    correctif ponctuel. Rien dessiné.
    Fiche 0014 — l'absence d'imprimante 3D est la sixième défaillance
    silencieuse du projet et la plus coûteuse : huit jours sans produire
    aucune erreur, parce que rien de ce qui a été fait ne s'est heurté à la
    machine absente. docs/00-cadrage.md est absent du dépôt, comme les trois
    autres documents signalés manquants dès la phase 0 : c'est ce trou
    documentaire qui a permis à l'erreur de survivre.
    Conséquence majeure : ToddlerBot est INCONSTRUCTIBLE. La doc amont dit
    « BambuLab printers are highly rec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
2026-09-28 Architecture en plaques sans précédent, et semelle livrée
    Fiche 0016 — correction vérifiée : Solo, Bolt et Upkie sont IMPRIMÉS EN
    3D. L'ODRI écrit « mostly 3D printed and off-the-shelves components » et
    « two-part 3D printed shell structures » ; Upkie imprime en PETG 0,2 mm
    sur Prusa i3 MK3S+.
    Point de fait : la justification par l'exemple n'était PAS entrée dans le
    dépôt — ni Solo, ni Bolt, ni Upkie, ni l'ODRI n'y figurent. La fiche 0015
    raisonne uniquement à partir de la contrainte, et cette chaîne est
    intacte. Ce qui manquait n'était pas une justification fausse à retirer
    mais un constat absent à ajouter : aucun projet open source accessible ne
    construit sa structu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
    [hardware.yaml]
2026-09-28 MEVITA vérifié, fiche 0016 corrigée, enveloppes d'actionneurs
    Fiche 0017 — le constat « aucun précédent en découpe métal » de la fiche
    0016 est FAUX. MEVITA (IEEE Humanoids 2025, arXiv 2508.17684, JSK Tokyo),
    MEVIUS (2409.14721) et MEVIUS2 (2603.22031) construisent en tôle
    découpée. Vérifié à la source, citation exacte du résumé : « most
    existing open-source bipedal robots are designed to be fabricated using
    3D printers, which limits their scalability in size and often results in
    fragile structures » — notre constat de la fiche 0014, publié.
    Confirmés : A7075 / A5052 / SUS304, quatre pièces soudées, commande
    automatique sur envoi de STEP via meviy (MISUMI).
    NON con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
2026-09-28 Correction libGL, échec dur par défaut, dépendances système cherchées
    1 — Trois paquets système manquaient à l'étage constructeur : libgl1,
    libx11-6, libexpat1. Établis en lisant les entrées NEEDED des 342 ELF du
    venv, en écartant les 106 bibliothèques embarquées dans les roues
    (suffixe de hachage auditwheel), et en confirmant par dpkg -S. OCCT se
    lie à libGL même sans affichage : importer OCP charge libTKOpenGl et
    libTKService.
    Rien de plus : ni mesa-utils, ni xvfb. Les transitives sont couvertes —
    vérifié, libgl1 tire libglvnd0 et libglx0, libx11-6 tire libxcb1.
    2 — Ce que je n'ai PAS pu vérifier : la construction de l'image. docker
    n'est ici qu'un relais Windows s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
    [semelle_apprentissage_P2_cutter_carton.dxf, semelle_apprentissage_P2_cutter_carton.step]
2026-09-28 Carton ondulé : procédé, matériau, anisotropie déclarée et fléchée
    Site en ligne sur yxor.fr. Correction de matériau.
    Ajouté : procédé cutter_carton_ondule et matériau carton_ondule,
    distincts de carton_plume. Épaisseur, saignée, rayon intérieur minimal et
    voile minimal à null — à mesurer. Le rayon dérive de l'épaisseur, il
    reste donc null tant qu'elle l'est.
    La pièce REFUSE de se construire sur ce procédé : garde-fou de la fiche
    0015, message rendu net et sortie en code 2 au lieu d'une trace.
    Anisotropie : une cannelure donne une direction forte le long des arches
    et une direction faible en travers. Cinq conséquences consignées, dont
    celle qui compte — deux pi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
    [hardware.yaml, semelle_apprentissage_P2_cutter_carton.dxf, semelle_apprentissage_P2_cutter_carton.step]
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2026-09-29 Trois états pour une valeur absente, et trois défauts d'affichage
    Quatre défauts relevés sur le site en ligne, sur mobile.
    1. Le tableau Fabrication affichait « cannelures : non déterminé » en
    rouge alors que le matériau est isotrope. L'orientation n'est pas à
    mesurer : elle n'existe pas. Le site inversait la distinction que le
    projet tient depuis la fiche 0013.
    Cause générale : val() traitait tout null de la même façon. Fiche
    0020 — un null déclare son état parmi a_mesurer, sans_objet et
    se_deduira, a_mesurer restant le défaut. Les conditions sont écrites
    dans params/nullites.yaml, jamais dans le code du site.
    Inventaire : 36 valeurs nulles dan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
    [semelle_apprentissage.origines.yaml]
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2026-09-29 Quatre vérifications, correction des licences et de la torsion, veille
    VÉRIFICATIONS (fiche 0028)
    (a) BambuStudio #11560 existe, ouverte le 2026-07-15, et dit exactement
    ce qui était rapporté — y compris le CPU épinglé et l'ASLR. Écarts
    non cosmétiques, dont une différence de mouvement réelle (feedrate),
    9 paires sur 15. MAIS : zéro commentaire, aucun label, aucune
    réponse de l'éditeur depuis deux mois et demi. Crédible, non
    corroborée. Impact nul aujourd'hui : nous ne produisons pas de
    G-code.
    (b) LAN-only Mode existe et coupe le pilotage par le nuage, mais « aucune
    connexion sortante » n'est établi par aucune source — cela demande
    une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
2026-09-29 Règle d'achat en trois branches, et migration vers quatre tables
    1. RÈGLE D'ACHAT (fiche 0027, acceptée). Trois branches, la troisième
    venant de Jeremy : (a) lié à une pièce -> la pièce doit être
    coupable, critère vérifiable ; (b) outillage -> AUCUN critère
    automatique, décision de Jeremy, hors de portée de l'assistant ;
    (c) l'assistant ne propose jamais un achat de lui-même. La branche
    (b) est celle que je n'aurais pas dû essayer de couvrir : la déclarer
    explicitement sans critère la rend lisible. Ancienne règle barrée,
    pas effacée.
    2. MIGRATION (fiches 0026 et 0033, appliquées en une fois).
    hardware.yaml passe à machines / procedes / matieres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
    [hardware.yaml]
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2026-09-29 Six faux verts corrigés, verdict par pièce, fiches outillées
    POINT 5 D'ABORD. Six endroits où un contrôle passait pour une mauvaise
    raison, tous de la même forme : un résultat qui ne dépend pas de ce que
    le contrôle prétend inspecter.
    - Deux fourre-tout `**` couvraient 755 valeurs sur 1431 (54 %), rendant
    non_qualifie INATTEIGNABLE pour deux fichiers. controle_regles.py
    refuse désormais un motif captant plus de la moitié d'un fichier sans
    `fourre_tout: true` assumé.
    - ratios.** captait 73 % d'anthropometry depuis ce matin et déclarait
    `effectif: 6068` de nature echelle — une cote qui grandirait avec le
    robot. La nature echelle tombe de 81 à 49 valeurs.
    - Le détec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
    [semelle_apprentissage.origines.yaml]
2026-09-29 Dimensionnement thermique : la thèse Forget lue, et ce qui manque
    VÉRIFICATION (fiche 0038). Thèse lue directement sur le disque : 148
    pages, chapitre 5 p. 93-102. Le résumé de Jeremy est exact presque mot
    pour mot — les générateurs de mouvements ne retiennent que les maxima de
    couple et de vitesse, et c'est la température qui limite.
    Correction de détail : trois régions et non quatre. La figure porte
    quatre étiquettes mais le texte décrit zone sûre, zone de courte durée
    (démagnétisation, fonte du vernis d'isolation), et destruction au-delà ;
    « safe » et « non-safe » sont deux MODES d'exploitation, pas deux zones.
    Non vérifiable : la figure 5.1 est un graphique, ses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
2026-09-29 Un site périmé doit se reconnaître : le SHA du commit, jusque sur le papier
    Le vrai problème n'était pas la construction cassée — c'est qu'elle a
    échoué quatre heures en silence pendant que l'ancien conteneur servait
    un plan de découpe faux avec l'air d'être à jour.
    Je tranche : les deux pistes, plus une troisième qui compte davantage.
    1. PIED DE PAGE — date ET SHA court, avec la commande de comparaison.
    `git rev-parse --short=12 HEAD` suffit à trancher en deux secondes.
    2. FICHE ATELIER — le SHA en 30 px, encadré, avec ce qu'il faut en faire.
    3. ET SURTOUT LE PLAN A4. C'est LUI qu'on colle sur la matière, pas la
    page web. Il porte désormais :
    Genere l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
2026-09-29 L'empreinte du site doit se calculer PARTOUT de la même façon
    Constaté sur le site en ligne : Coolify ne passe pas SOURCE_COMMIT, et
    le SHA s'affichait « inconnu ». Le repli disait la vérité plutôt que
    d'inventer — bon comportement — mais il ne donnait rien à comparer.
    Défaut plus grave, trouvé en le vérifiant : en local la page aurait
    montré le SHA git, en Docker l'empreinte de repli. LES DEUX NE SE
    SERAIENT JAMAIS COMPARÉES. Un signal qu'on ne peut pas confronter ne
    signale rien — exactement la classe de faute qu'il devait corriger.
    Donc une seule grandeur, calculée de la même façon partout : l'empreinte
    sha256 du contenu de params/, parts/, scripts/ et web/. Et el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
2026-09-29 Une seule empreinte, partagée par le site et le plan papier
    Le plan A4 portait `git rev-parse`, le site l'empreinte de contenu :
    deux grandeurs qui ne se seraient jamais comparées. scripts/empreinte.py
    devient le module partagé — pages.py et la pièce l'importent.
    Les trois portent désormais la même valeur, vérifié : pied de page,
    fiche atelier, et le plan A4 qu'on colle sur la matière.
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2026-09-29 Chromium injoignable : six tentatives, constat et non contournement
    cdn.playwright.dev et storage.googleapis.com ne répondent pas depuis
    cette machine — zéro octet, http 000 — alors que GitHub, PyPI et
    googlechromelabs.github.io répondent. Ce n'est pas de la lenteur, c'est
    un blocage réseau.
    Contournements essayés et morts : apt ne propose qu'un paquet-passerelle
    snap et snapd est inactif sous WSL ; le Chrome de Windows démarre bien
    mais son port de débogage est bloqué par le pare-feu, ni par la
    passerelle ni par localhost.
    verifier_pages.py est écrit et complet. Il tournera sans modification le
    jour où un binaire existera. Je n'ai toujours pas vu une page et je ne
    prétends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
2026-09-29 Le CSS n'était pas cassé : les URL d'actifs n'étaient pas versionnées
    POINT 1, ET LE DIAGNOSTIC EST AILLEURS. La feuille est saine et
    correctement servie :
    - accolades équilibrées, 143 pour 143, commentaires 23 pour 23 ;
    - aucune règle imbriquée hors @media, aucune profondeur > 1 ;
    - `.repli{display:none}` bien présent comme règle de base, et le
    @media(max-width:620px) bien formé autour de .pliable et .repli ;
    - le fichier SERVI par yxor.fr est octet pour octet celui du dépôt,
    même sha256.
    LA CAUSE : nginx sert /assets/ et /fichiers/ avec `expires 7d`, sur des
    URL SANS version. Les règles .repli datent de 11 h 13 aujourd'hui
    (aa719c0). Un navigateur ayant chargé le site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
2026-09-29 Repesée : 649 g/m2 a 2,5 %, et le profil de cannelure devient douteux
    UNITÉ CORRIGÉE À LA LECTURE. Le relevé disait « 22 x 14 mm » : en
    millimètres, 20 g sur 308 mm2 donneraient 65 000 g/m2. Lu en
    centimètres, 649 g/m2, à 2 % du relevé du matin. Correction consignée
    dans mesures.yaml plutôt que faite en silence.
    LES 635 g/m2 DU MATIN TENAIENT. Leur intervalle allait de 556 à 714 ; la
    nouvelle valeur tombe dedans. La première pesée est REMPLACÉE et non
    effacée — elle garde sa valeur de vérification croisée.
    CE QUE LA REPESÉE N'A PAS CHANGÉ. masse surfacique 12,5 -> 2,5 %, un
    facteur cinq. Densité 19,0 -> 14,5 %, presque rien : le terme dominant a
    changé de côté,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
    [hardware.yaml]
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2026-09-29 Fiche 0044 : la semelle publiée n'est pas celle qui a été coupée
    Le contour coïncide — aucune cote d'échelle ne dépend de la matière —
    mais la page affirme carton_plume 5,0 mm quand la pièce sur la table est
    en carton ondulé double de 3,5 mm. Une affirmation exacte dans sa forme
    et fausse dans son référent.
    Le nœud : une variante fidèle à la matière serait MOINS fidèle au geste.
    Son rayon vaudrait 1,75 mm par 0,5 x épaisseur, alors que R 2,5 a déjà
    été difficile à couper à la main, deux passes dans les angles. On
    corrigerait une fausseté de traçabilité par une fausseté de
    fabricabilité.
    Quatre voies pour le rayon, aucune satisfaisante seule. Recommandation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
2026-09-29 Passation : ce que la session sait et que le dépôt ne porte pas
    Six choses tenues pour acquises et jamais vérifiées ou écrites :
    - le réglet du plan A4 n'a jamais été imprimé ni mesuré ;
    - le simulateur JS et zoom.js n'ont jamais tourné, et le correctif
    d'ordre des points leur a été appliqué sans pouvoir l'exécuter ;
    - le blocage de Chromium est un constat, pas un diagnostic — zéro octet
    observé, cause inconnue ;
    - les rendus de contrôle ont été jugés à l'œil, sans critère écrit ;
    - une hypothèse sous-pondérée : une double à cannelures FINES explique
    3,5 mm sans invoquer d'écrasement, et rendrait la mention « borne
    haute » de la densité caduque ;
    -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
2026-09-29 État des lieux de la nuit : audit exhaustif, rien de corrigé
    docs/etat-des-lieux-2026-09-29-nuit.md, seul fichier ajouté. Chaque
    affirmation porte son statut : vérifié, déclaré ou déduit. Tous les
    scripts ont été relancés, sauf sim/view.py.
    Cinq défauts critiques, tous dans l'appareil de contrôle : garde de
    venv à sens unique, refus d'achat inexistant, code de retour de
    index_fiches ignoré, second « Amendée par » perdu par l'index, semelle
    publiée en carton-plume alors que la pièce coupée est en ondulé.
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2026-09-29 Lot A.1 — Licence amont : CC BY-NC-SA, et la clause SA dite
    CLAUDE.md et fiche 0001 corrigés, ligne exacte du README amont citée.
    Conséquence de SA : aucune géométrie amont dans une pièce YXOR. Les
    valeurs numériques extraites restent une question juridique ouverte.
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2026-09-29 Lot A — clôture : 4 tests, et l'empreinte du site ne concorde plus
    Dépôt 2f589293ec, site dcbda4512c. Déduit : Coolify réécrit le
    Dockerfile (ARG injectés) que le point 3 fait entrer dans l'empreinte.
    Non corrigé : trois voies consignées, décision à prendre.
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2026-09-30 Exigences d'actionnement P2 : premier chiffrage depuis une marche simulée
    30 actionneurs inventoriés depuis le MJCF et default.yml amont (lus
    comme données). Marche relancée (15 s, 751 pas) : 9 actionneurs de
    jambe sur 12 écrêtés par le modèle de moteur, leurs pointes sont des
    bornes basses. Passage à P2 par similitude, hypothèses écrites, facteur
    1,5 à valider.
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2026-09-30 Dimensionnement inverse : la classe d'actionneur fixe la taille maximale
    Catalogue sourcé de 7 candidats (params/actionneurs.yaml), budget par
    phase (params/budget.yaml), scripts/dimensionnement.py avec boucle sur
    la masse et contrôle de cohérence (ToddlerBot, Zeroth-01) qui arrête
    tout s'il échoue ; test qui prouve qu'il sait échouer. Tous les
    résultats sont des plafonds optimistes (roulis de hanche écrêté en P1).
    RS02 : 6 N·m retenu sur consigne, le PDF constructeur dit 7.
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2026-10-01 Refonte R5 : verdicts des 13 fiches (Jeremy) ; fiche 0066 règle d'achat (remplace 0027) ; CLAUDE.md (règle 5, contrôles, journal, lecture) ; README = état courant ; cadrage réduit à vision et méthode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
    [hardware.yaml]
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2026-10-01 Rayon intérieur minimal = max(0,5 × épaisseur, limite de machine) : règle unique dans procedes.py, appliquée par profil, la pièce et le simulateur (via fixes) ; contrôles réglage et pièce en ≥ ; test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
    [hardware.yaml]
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2026-10-02 Fiche 0067 (Jeremy, 2026-10-02) : jambes de S mixtes, RS02 au roulis et au tangage de hanche et au genou, RS00 ailleurs ; remplace la 0065 ; configuration_S.yaml lue par la grille et le contrôle des 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
    [test_configuration_S.py]
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2026-10-03 Jambe basse en plaques : écart ANSUR de la cheville (RS00, +81 mm de jambe), parts/jambe_basse.py (pied, liaison A/B/C à tenons, tibia en caisson, chape de genou, factices carton), DXF, planches A4 (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
    [hardware.yaml]
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2026-10-04 Fiche 0068 (Jeremy, 2026-10-04) : cheville de S sans roulis, 5 axes par jambe ; ankle_roll retiré (joints, configuration_S, squelette v3 26 DDL, dimensionnement), besoins écartés annoncés ; jambe bas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
    [joints.yaml, test_configuration_S.py]
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2026-10-06 Simulations de marche et de relevé (phase 3b, aucune décision) : LeRobot Humanoid vérifié et corrigé, marches T1/G1/ToddlerBot et relevé sur CPU, couples sans dimension, référence prudente par articu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
    [test_simulations_marche.py]
2026-10-06 Outils de clôture versés (liens, contradictions ; décision de Jeremy) ; loi de masse allométrique en VARIANTE (b = 1,995 [1,814 ; 2,176] sur 31 bipèdes) ; grille de S : en-tête périmé corrigé
    [test_controles_cloture.py]
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2026-10-08 Lot 4a sexies : 12S décidé par Jeremy (fiche 0072) ; explorateur 10× plus rapide à résultats identiques ; saut corrigé (géométrie cohérente) ; coupure 2,5/3,0/3,2 V en variante ; bornes proposées ; c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
    [puissance.yaml]
2026-10-08 Lot 4a septies : coupure à 3,0 V (Jeremy) ; seul le tronc s'allonge (couples à la jambe réelle, centre de gravité) ; chaîne de puissance à l'échelle et variante compacte (relevé G) ; étude du saut se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
    [puissance.yaml]
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2026-10-08 YXOR Kit : fiche 0075 (Jeremy : niveaux 0-4, debout en Feetech, option progressive, recyclage, assemblage B, Feetech aux petits axes de la gamme) ; option progressive (secteur 12 V, batterie au nivea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
    [hardware.yaml]
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2026-10-09 Étude « familles de petits servos à bus » (aucune décision) : marché versé (31 modèles, 7 familles, 63 sources) ; scripts/servos_bus.py et docs/servos-bus-2026-10.md ; aucune famille ne tient le Lab 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
    [servos_bus.yaml]
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2026-10-09 Relevé des catégories absentes (aucun calcul, aucune décision) : params/capteurs.yaml, params/temps_reel.yaml, chargeurs 12S (puissance.yaml), Hailo-8 M.2 (calculateurs.yaml), actionneurs complémenta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
    [calculateurs.yaml, puissance.yaml]
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

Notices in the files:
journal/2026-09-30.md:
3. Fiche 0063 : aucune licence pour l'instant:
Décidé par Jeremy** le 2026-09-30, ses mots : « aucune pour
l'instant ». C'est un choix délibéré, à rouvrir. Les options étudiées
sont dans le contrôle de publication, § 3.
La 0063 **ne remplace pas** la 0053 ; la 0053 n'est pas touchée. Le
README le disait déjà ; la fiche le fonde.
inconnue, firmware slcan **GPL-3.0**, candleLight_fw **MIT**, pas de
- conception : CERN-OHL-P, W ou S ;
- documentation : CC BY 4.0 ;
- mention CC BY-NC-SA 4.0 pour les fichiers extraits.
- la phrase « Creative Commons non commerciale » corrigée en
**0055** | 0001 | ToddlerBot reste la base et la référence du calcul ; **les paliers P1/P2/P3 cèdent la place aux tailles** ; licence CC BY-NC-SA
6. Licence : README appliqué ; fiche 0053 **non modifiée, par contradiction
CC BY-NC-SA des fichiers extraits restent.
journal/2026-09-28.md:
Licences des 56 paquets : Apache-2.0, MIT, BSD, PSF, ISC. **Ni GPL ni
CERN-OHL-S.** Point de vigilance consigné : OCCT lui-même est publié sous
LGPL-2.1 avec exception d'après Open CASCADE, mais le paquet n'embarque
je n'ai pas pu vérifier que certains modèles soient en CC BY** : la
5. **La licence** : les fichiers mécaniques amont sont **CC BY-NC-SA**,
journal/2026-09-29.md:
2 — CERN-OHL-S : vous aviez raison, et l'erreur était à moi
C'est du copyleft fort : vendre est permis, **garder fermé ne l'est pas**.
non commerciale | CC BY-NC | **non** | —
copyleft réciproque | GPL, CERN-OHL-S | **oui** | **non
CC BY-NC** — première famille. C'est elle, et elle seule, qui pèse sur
